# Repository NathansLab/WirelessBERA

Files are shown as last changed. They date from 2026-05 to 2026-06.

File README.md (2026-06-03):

# Wireless BERA

**Wireless Biopotential Electrode Recording Amplifier**

A wireless, battery-powered biopotential recording system for EEG and auditory brainstem response (ABR/BERA) measurements.

> **BERA** stands for two things in this project:
> - **B**rainstem **E**voked **R**esponse **A**udiometry — the clinical application
> - **B**iopotential **E**lectrode **R**ecording **A**mplifier — the hardware

---

## Hardware

**MCU:** ESP32-S3-WROOM-1 — Wi-Fi 802.11 b/g/n + Bluetooth 5.0 LE

**Analog Front-End:**
- LTC6373 programmable-gain instrumentation amplifier (Gain: 0.25, 0.5, 1, 2, 4, 8, 16)
- TAC5212 24-bit ADC via I²S
- Infineon IM73A135 differential MEMS microphone (stimulus/environment monitoring)
- Driven Right Leg (DRL) circuit via OPA376 (active CMR)

**Power** — see [PowerArchitecture.pdf](docs/PowerArchitecture.pdf):

Power Architecture
- BQ24074 single-cell Li-Ion charger
- TPS63000 buck-boost → 3.5 V regulated
- TPS65132W dual charge-pump → ±5.5 V raw
- TPS7A39 dual ultra-low-noise LDO → ±5 V (analog section)
- TPS7A94 LDO → 3.3 V analog
- TPS7A2033 LDO → 3.3 V digital
- Star-topology and LC filters on all analog supply rails

**Peripherals:** MicroSD (SDMMC 4-bit), USB-C (USB 2.0 + ESD)

**PCB:** 4-layer, split GNDA/GNDD

### Daughterboard
Optional plug-in for standalone LTC6373 evaluation at fixed Gain = 16. Stacking multiple daughterboards parallels the INA inputs, reducing equivalent input noise by √n.

---

>  **v1.0 — Pre-production prototype. Not yet fabricated.**

## 3D Renderings

### Stacked Assembly (Main Board + 3x Daughterboards)
Three LTC6373 Daughterboards stacked on top of the main Wireless BERA board to parallel the inputs and reduce equivalent input noise by $\sqrt{n}$.

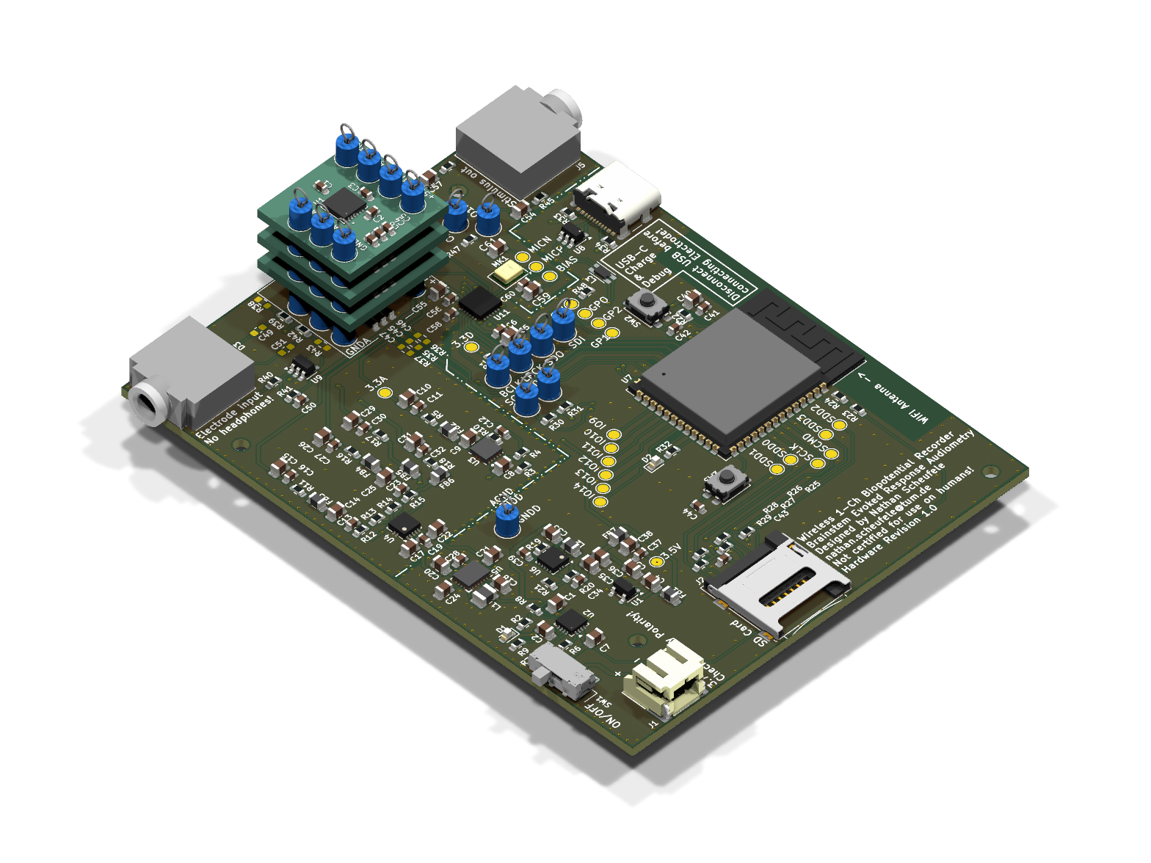
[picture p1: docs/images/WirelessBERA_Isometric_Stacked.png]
Wireless BERA Stacked Isometric


---

## Tools

- **EDA:** KiCad 10
- **Fabrication target:** Aisler (4-layer, HASL)
- **Firmware:** ESP-IDF (ESP32-S3) — see `firmware/`
- **Hardware Auditing & Design Review:** [kicad-happy](https://github.com/aklofas/kicad-happy) (located locally in `kicad-happy/`)

### Running the Hardware Audit
To perform a full design review of the schematic, layout, and EMC pre-compliance:
```bash
# Schematic Analysis
/opt/homebrew/bin/python3 kicad-happy/skills/kicad/scripts/analyze_schematic.py hardware/WirelessBERA.kicad_sch --output scratch/sch_analysis.json

# PCB Layout Analysis
/opt/homebrew/bin/python3 kicad-happy/skills/kicad/scripts/analyze_pcb.py hardware/WirelessBERA.kicad_pcb --full --output scratch/pcb_analysis.json

# Cross-Domain Verification
/opt/homebrew/bin/python3 kicad-happy/skills/kicad/scripts/cross_analysis.py --schematic scratch/sch_analysis.json --pcb scratch/pcb_analysis.json --output scratch/cross_analysis_results.json

# EMC Pre-Compliance Audit
/opt/homebrew/bin/python3 kicad-happy/skills/emc/scripts/analyze_emc.py --schematic scratch/sch_analysis.json --pcb scratch/pcb_analysis.json --output scratch/emc_analysis.json
```
---

## Upstream Tool Updates & Custom Features

The local copy of `kicad-happy/` contains custom extensions (such as the custom footprint/package verification checks in `datasheet_verify.py` and saving logic in `analyze_schematic.py`). 

To pull future improvements from the upstream [kicad-happy repository](https://github.com/aklofas/kicad-happy) while keeping custom modifications:

1. Configure the upstream remote inside `kicad-happy/`:
   ```bash
   cd kicad-happy
   git remote add upstream https://github.com/aklofas/kicad-happy.git
   ```
2. Fetch and merge upstream changes:
   ```bash
   git fetch upstream
   git merge upstream/main
   ```

> [!IMPORTANT]
> **AI Agent Reminder / Instruction:**
> When resuming or initiating a design audit, check if there are new updates in the upstream `kicad-happy` repository. Fetch them, merge them into our local directory, and verify that the custom footprint verification code inside `skills/datasheets/scripts/datasheet_verify.py` and output logic inside `skills/kicad/scripts/analyze_schematic.py` are preserved and function correctly.

---

## Author

Nathan Scheufele

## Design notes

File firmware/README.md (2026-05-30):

# Firmware
ESP-IDF firmware for ESP32-S3 will be added here.

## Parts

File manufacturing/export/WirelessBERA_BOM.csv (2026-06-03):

Reference | Qty | Value | Footprint | MPN | Manufacturer | Chosen_Distributor | Datasheet | Validated | DNP | Notes
C1,C2,C7,C18,C20,C21,C24 | 7 | 4.7u | Capacitor_SMD:C_0805_2012Metric | C0805C475K4PACTU
C3-C5,C8-C10,C14,C15,C17,C22,C25,C26,C29,C31,C33,C35,C36,C38,C56 | 19 | 10u | Capacitor_SMD:C_0805_2012Metric | C0805C106K4PACTU
C6,C11,C16,C19,C27,C30,C32,C37,C39,C41-C47,C57,C61 | 18 | 100n | Capacitor_SMD:C_0603_1608Metric | C0603C104K5RACTU
C12,C50,C59 | 3 | 1u | Capacitor_SMD:C_0603_1608Metric | C0603C105K8PACTU
C13,C23 | 2 | 10n | Capacitor_SMD:C_0603_1608Metric | C0603C103G8GACTU
C28 | 1 | 2.2u | Capacitor_SMD:C_0603_1608Metric | C0603C225K8PACTU
C34 | 1 | 4.7p | Capacitor_SMD:C_0603_1608Metric | C0603C479C4HACTU
C40,C55,C58,C60,C62 | 5 | 22u | Capacitor_SMD:C_0805_2012Metric | GRM21BR60J226ME39L
C48,C53 | 2 | 10u | Capacitor_SMD:C_0603_1608Metric | GRM188R61C106KE15D
C49,C52 | 2 | TBD | Capacitor_SMD:C_0603_1608Metric |  |  |  |  |  | DNP
C51 | 1 | 1n | Capacitor_SMD:C_0603_1608Metric | C1608C0G1H102J080AE
C54 | 1 | 180p | Capacitor_SMD:C_0603_1608Metric | C0603C181J5GACTU
D1,D2 | 2 | LED | LED_SMD:LED_0603_1608Metric | 150060VS75000
D3 | 1 | CMKD6000 | Package_TO_SOT_SMD:SOT-363_SC-70-6 | CMKD6000 TR PBFREE |  |  | https://www.mouser.de/datasheet/3/312/1/CMKD6000.pdf
FB1-FB7 | 7 | FerriteBead | Inductor_SMD:L_0805_2012Metric | 742792040 |  |  | https://www.we-online.com/en/components/products/WE-CBF#742792040
J1 | 1 | Conn_01x02 | Connector_JST:JST_PH_S2B-PH-SM4-TB_1x02-1MP_P2.00mm_Horizontal | S2B-PH-SM4-TB(LF)(SN)
J2,J3 | 2 | PinHeader_01x01_2.54mm_Vertical | Connector_PinHeader_2.54mm:PinHeader_1x01_P2.54mm_Vertical | 61300111121 |  |  | https://www.we-online.com/components/products/datasheet/61300111121.pdf
J4 | 1 | Micro_SD_Card | Connector_Card:microSD_HC_Wuerth_693072010801 | 693072010801 |  |  | https://www.we-online.com/components/products/datasheet/693072010801.pdf
J5 | 1 | USB_C_Receptacle | Connector_USB:USB_C_Receptacle_GCT_USB4105-xx-A_16P_TopMnt_Horizontal | 629722000214 |  |  | https://www.usb.org/sites/default/files/documents/usb_type-c.zip
J6,J11 | 2 | AudioJack3 | Connector_Audio:Jack_3.5mm_CUI_SJ1-3523N_Horizontal | SJ1-3523N
J7,J8,J10,J12 | 4 | PinHeader_01x04_2.54mm_Vertical | Connector_PinHeader_2.54mm:PinHeader_1x04_P2.54mm_Vertical | 61300411121 |  |  | https://www.we-online.com/components/products/datasheet/61300411121.pdf
J9 | 1 | PinHeader_01x03_2.54mm_Vertical | Connector_PinHeader_2.54mm:PinHeader_1x03_P2.54mm_Vertical | 61300311121 |  |  | https://www.we-online.com/components/products/datasheet/61300311121.pdf
J13 | 1 | PinHeader_01x02_2.54mm_Vertical | Connector_PinHeader_2.54mm:PinHeader_1x02_P2.54mm_Vertical | 61300211121 |  |  | https://www.we-online.com/components/products/datasheet/61300211121.pdf
L1 | 1 | 4.7uH | Inductor_SMD:L_1008_2520Metric | 1269AS-H-4R7M=P2 |  |  | https://www.murata.com/en-us/products/productdata/8801124458526/DS0028.pdf
L2 | 1 | 2.2u | Inductor_SMD:L_0805_2012Metric | LQM21PN2R2NGCD |  |  | https://www.murata.com/en-us/products/productdata/8801124458526/DS0028.pdf
L3 | 1 | WE_CNSW_744232090 | Inductor_SMD:L_CommonMode_Wurth_WE-CNSW-1206 | 744232090 |  |  | https://www.we-online.com/components/products/datasheet/744232090.pdf
MK1 | 1 | IM73A135V01 | Sensor_Audio:Infineon_PG-LLGA-5-2 | IM73A135V01XTSA1 |  |  | https://www.infineon.com/dgdl/Infineon-IM73A135-DataSheet-v01_00-EN.pdf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
R1,R5,R11,R16-R18 | 6 | 1R | Resistor_SMD:R_0603_1608Metric | CRCW06031R00FKEA
R2,R7,R33,R34 | 4 | 5.1k | Resistor_SMD:R_0603_1608Metric | CRCW06035K10FKEA
R3,R4,R6,R13,R14,R22-R31,R43,R50 | 17 | 10k | Resistor_SMD:R_0603_1608Metric | CRCW060310K0FKEA
R8 | 1 | 1.1k | Resistor_SMD:R_0603_1608Metric | CRCW06031K10FKEA
R9 | 1 | 2.2k | Resistor_SMD:R_0603_1608Metric | CRCW06032K20FKEA
R10 | 1 | 22.1k | Resistor_SMD:R_0603_1608Metric | CRCW060322K1FKEA
R12 | 1 | 32.4k | Resistor_SMD:R_0603_1608Metric | CRCW060332K4FKEA
R15 | 1 | 42.2k | Resistor_SMD:R_0603_1608Metric | CRCW060342K2FKEA
R19 | 1 | 100R | Resistor_SMD:R_0603_1608Metric | CRCW0603100RFKEA
R20 | 1 | 1.2M | Resistor_SMD:R_0603_1608Metric | CRCW06031M20FKEA
R21 | 1 | 200k | Resistor_SMD:R_0603_1608Metric | CRCW0603200KFKEA
R32 | 1 | 330R | Resistor_SMD:R_0603_1608Metric | CRCW0603330RFKEA
R35-R37 | 3 | 10k | Resistor_SMD:R_0603_1608Metric | CRCW060310K0FKEA |  |  |  |  | DNP
R38,R45 | 2 | TBD | Resistor_SMD:R_0603_1608Metric |  |  |  |  |  | DNP
R39,R42,R44 | 3 | 1M | Resistor_SMD:R_0603_1608Metric | CRCW06031M00FKEA
R40 | 1 | 4.99k | Resistor_SMD:R_0603_1608Metric | CRCW06034K99FKEA
R41 | 1 | 110k | Resistor_SMD:R_0603_1608Metric | CRCW0603110KFKEA
R46,R49 | 2 | 0R | Resistor_SMD:R_0603_1608Metric | CRCW06030000Z0EA
R47,R48 | 2 | 10R | Resistor_SMD:R_0603_1608Metric | CRCW060310R0FKEA
SW1 | 1 | SW_SPDT | Button_Switch_SMD:SW_SPDT_CK_JS102011SAQN | JS102011SAQN |  |  | https://www.ckswitches.com/media/1422/js.pdf
SW2,SW3 | 2 | SW_Push | Button_Switch_SMD:SW_SPST_EVQP2_MiddlePushTravel_H2.5mm | EVQ-P2P02M |  |  | https://4donline.ihs.com/images/VipMasterIC/IC/PANA/PANAS38695/PANAS38695-1.pdf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
U1 | 1 | TPS7A2033PDBVR | Package_TO_SOT_SMD:SOT-23-5 | TPS7A2033PDBVR |  |  | https://www.ti.com/lit/ds/symlink/tps7a20.pdf
U2 | 1 | BQ24074RGT | Package_DFN_QFN:VQFN-16-1EP_3x3mm_P0.5mm_EP1.6x1.6mm | BQ24074RGTR |  |  | http://www.ti.com/lit/ds/symlink/bq24074.pdf
U3 | 1 | TPS7A94 | BERA Project Specific Footprints:TPS7A94_WSON-10 | TPS7A9401DSCR |  |  | https://www.ti.com/lit/ds/symlink/tps7a94.pdf
U4 | 1 | TPS7A39 | Package_SON:Texas_S-PVSON-N10_ThermalVias | TPS7A3901DSCR |  |  | https://www.ti.com/lit/ds/symlink/tps7a39.pdf
U5 | 1 | TPS65132W | BERA Project Specific Footprints:TPS65132W_WQFN-20-TI | TPS65132WRVCR |  |  | https://www.ti.com/lit/gpn/tps65132
U6 | 1 | TPS63000 | Package_SON:Texas_DRC0010J_ThermalVias | TPS63000DRCR |  |  | http://www.ti.com/lit/ds/symlink/tps63000.pdf
U7 | 1 | ESP32-S3-WROOM-1 | RF_Module:ESP32-S3-WROOM-1 | ESP32-S3-WROOM-1-N16R8 |  |  | https://www.espressif.com/sites/default/files/documentation/esp32-s3-wroom-1_wroom-1u_datasheet_en.pdf
U8 | 1 | WE-TVS-82400102 | Package_TO_SOT_SMD:SOT-23-6 | 82400102 |  |  | https://www.we-online.com/components/products/datasheet/82400102.pdf
U9 | 1 | OPA376xxDBV | Package_TO_SOT_SMD:SOT-23-5 | OPA376AIDBVR |  |  | http://www.ti.com/lit/ds/symlink/opa376.pdf
U10 | 1 | LTC6373 | BERA Project Specific Footprints:LTC6373_DFN-12 | LTC6373IDFM#PBF |  |  | https://www.analog.com/media/en/technical-documentation/data-sheets/ltc6373.pdf
U11 | 1 | TAC5212 | BERA Project Specific Footprints:TAC5212_VQFN24 | TAC5212IRGER |  |  | https://www.ti.com/lit/gpn/tac5212

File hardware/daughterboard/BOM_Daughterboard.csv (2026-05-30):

Refs | Value | Footprint | Qty | DNP
C1 | 180p | Capacitor_SMD:C_0603_1608Metric | 1
C2 | 10u | Capacitor_SMD:C_0603_1608Metric | 1
C3 | 10u | Capacitor_SMD:C_0603_1608Metric | 1
C4 | 100n | Capacitor_SMD:C_0603_1608Metric | 1
C5 | 100n | Capacitor_SMD:C_0603_1608Metric | 1
C6 | 100n | Capacitor_SMD:C_0603_1608Metric | 1
H1 | Header_Pin | TestPoint:TestPoint_Loop_D2.60mm_Drill0.9mm_Beaded | 1
H2 | Header_Pin | TestPoint:TestPoint_Loop_D2.60mm_Drill0.9mm_Beaded | 1
H3 | Header_Pin | TestPoint:TestPoint_Loop_D2.60mm_Drill0.9mm_Beaded | 1
H4 | Header_Pin | TestPoint:TestPoint_Loop_D2.60mm_Drill0.9mm_Beaded | 1
H5 | Header_Pin | TestPoint:TestPoint_Loop_D2.60mm_Drill0.9mm_Beaded | 1
H6 | Header_Pin | TestPoint:TestPoint_Loop_D2.60mm_Drill0.9mm_Beaded | 1
H7 | Header_Pin | TestPoint:TestPoint_Loop_D2.60mm_Drill0.9mm_Beaded | 1
U1 | LTC6373 | BERA Project Specific Footprints:LTC6373_DFN-12 | 1

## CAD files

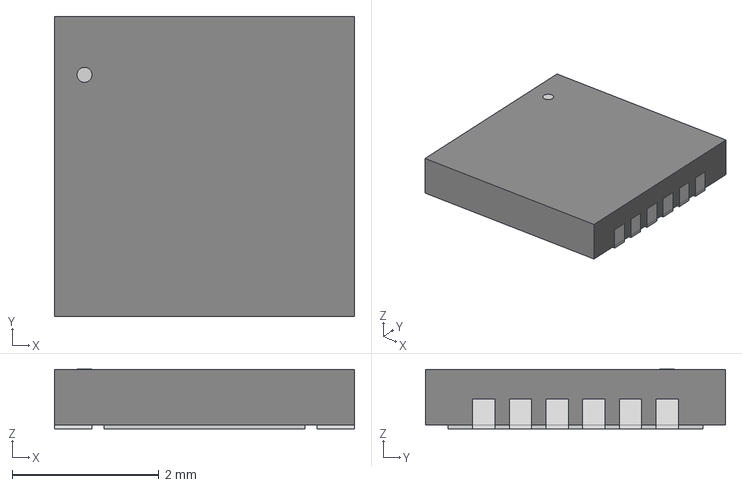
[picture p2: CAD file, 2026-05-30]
hardware/daughterboard/3d_models/LTC6373.step
4.09 x 4.09 x 0.815 mm

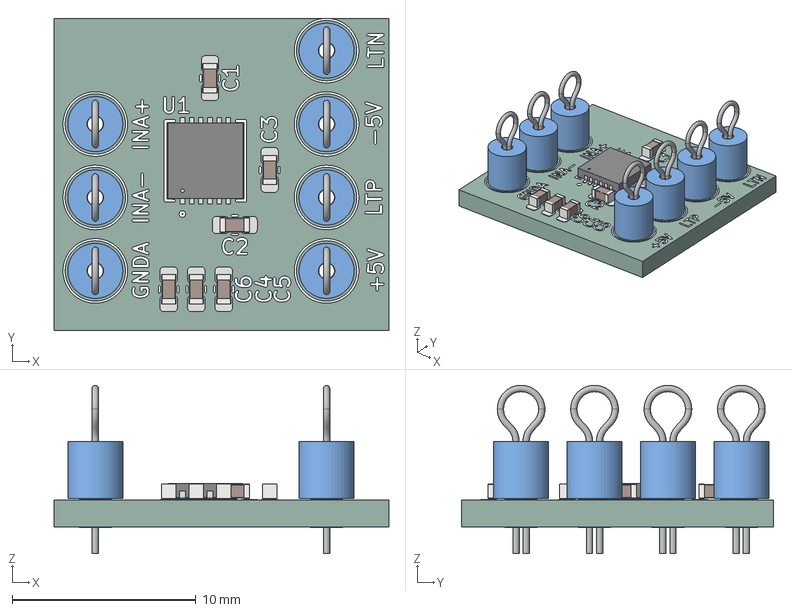
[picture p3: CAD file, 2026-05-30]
hardware/daughterboard/LTC6373_Daughterboard.step
18.2 x 17.0 x 9.17 mm
C_0603_1608Metric x 6
TestPoint_Loop_D2.60mm_Drill0.9mm_Beaded x 7
LTC6373
LTC6373_Daughterboard_pad
LTC6373_Daughterboard_silkscreen
LTC6373_Daughterboard_PCB

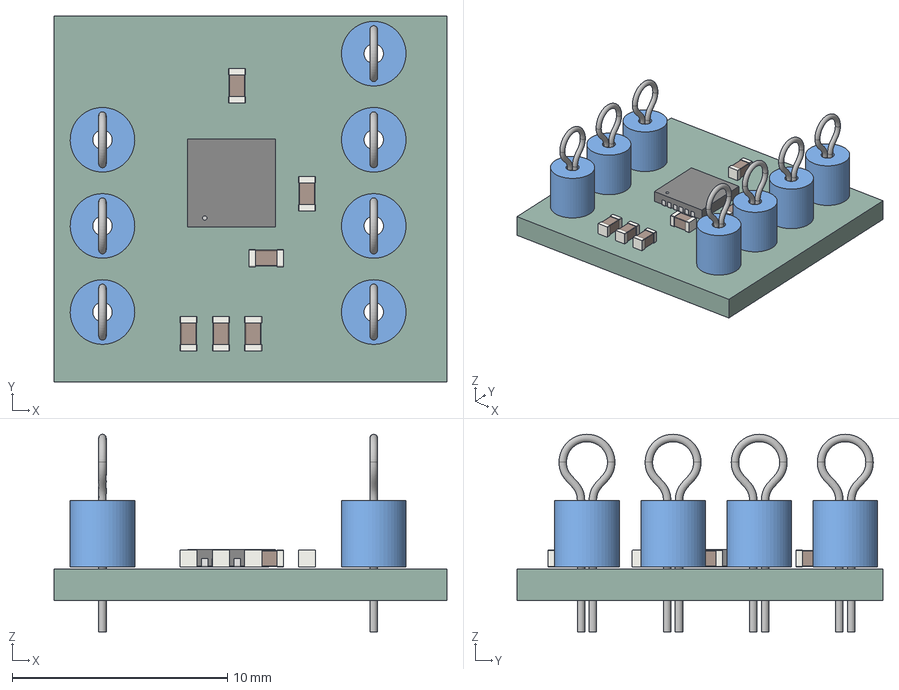
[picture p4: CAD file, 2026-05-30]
manufacturing/export/LTC6373_Daughterboard.step
18.2 x 17.0 x 9.17 mm
C_0603_1608Metric x 6
TestPoint_Loop_D2.60mm_Drill0.9mm_Beaded x 7
LTC6373
LTC6373_Daughterboard_PCB

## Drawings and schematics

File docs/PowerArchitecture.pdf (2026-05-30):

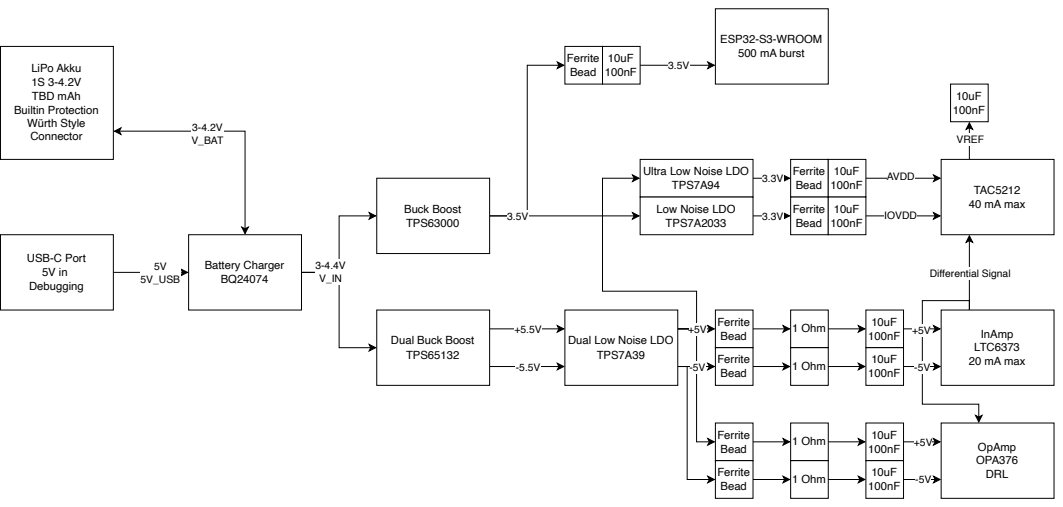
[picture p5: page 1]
LiPo Akku 1S 3-4.2V TBD mAh Builtin Protection Würth Style Connector; 5V 5V_USB; USB-C Port 5V in Debugging; 3-4.2V V_BAT; Battery Charger BQ24074; 3.3V Buck Boost; TPS63000; ESP32-S3-WROOM 500 mA burst; VREF; TAC5212 40 mA max; Ferrite; Bead; 1 Ohm; Differential Signal; InAmp LTC6373 20 mA max; Ferrite Bead; AVDD 10uF; IOVDD 10uF; OpAmp OPA376 DRL; 10uF 100nF 1 Ohm

100nF 3.3V Ultra Low Noise LDO
TPS7A94

Low Noise LDO
TPS7A2033

Dual Buck Boost
TPS65132

Dual Low Noise LDO
TPS7A39

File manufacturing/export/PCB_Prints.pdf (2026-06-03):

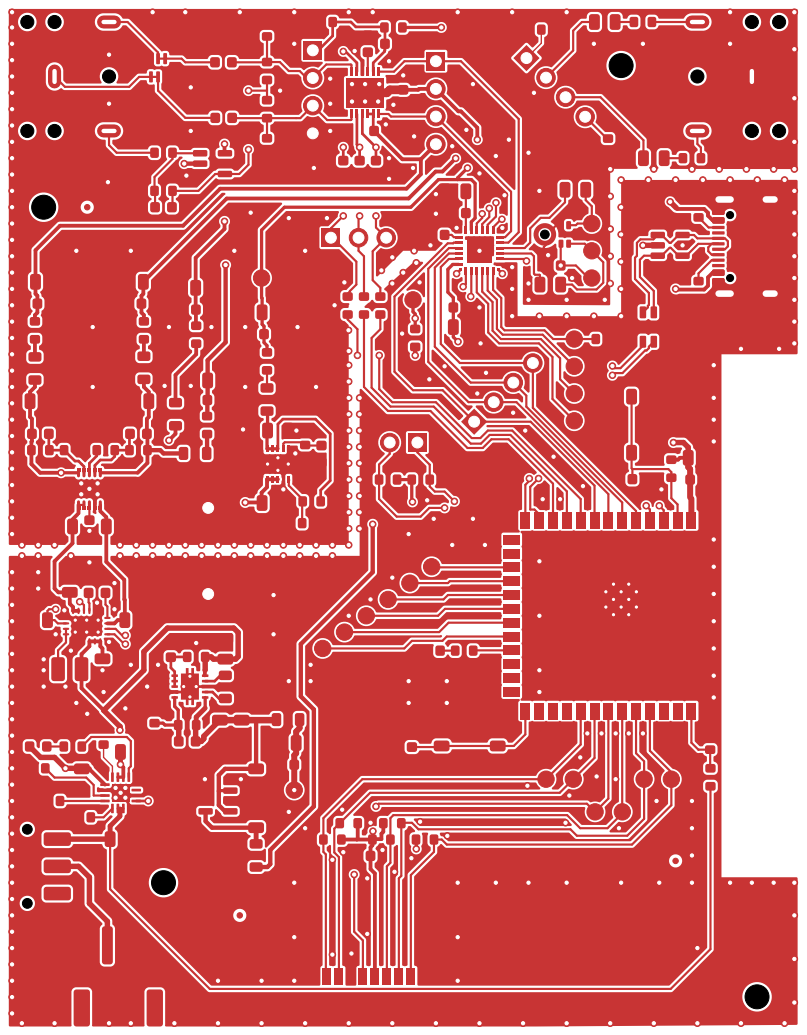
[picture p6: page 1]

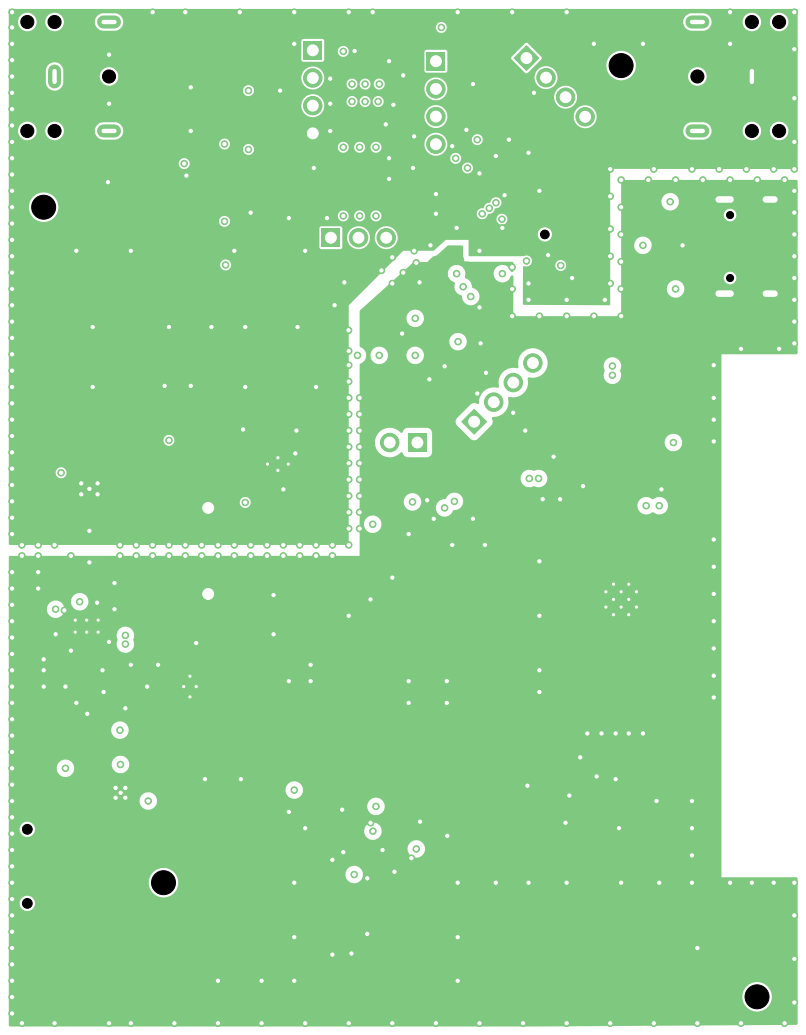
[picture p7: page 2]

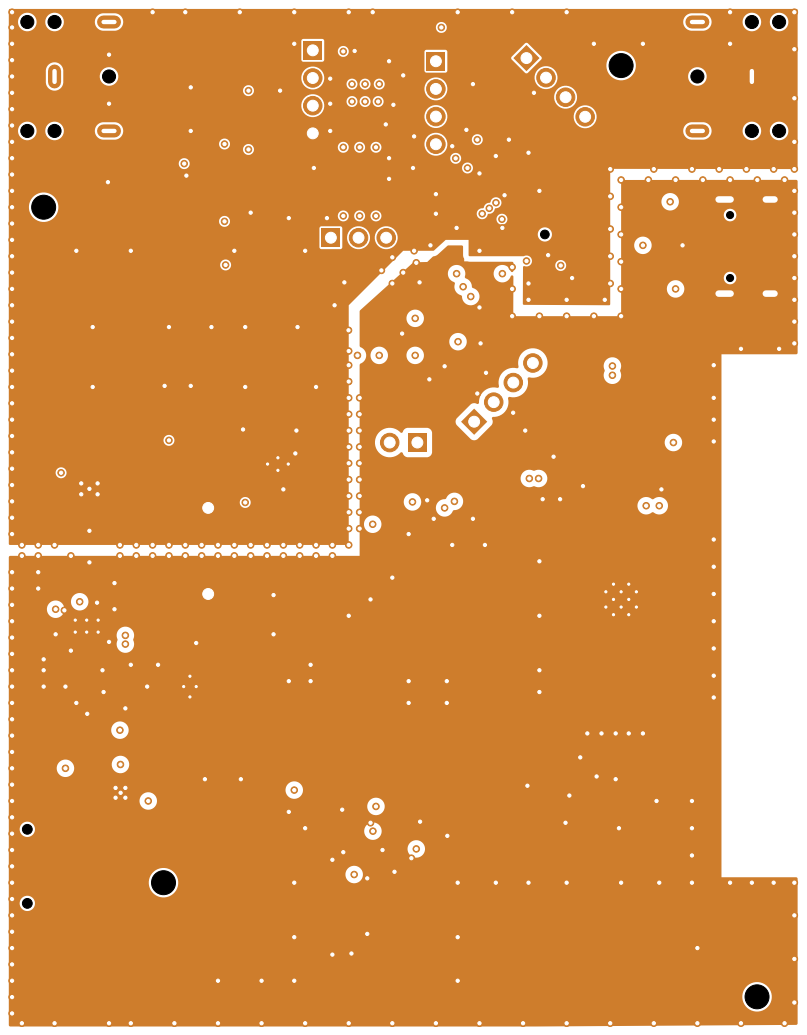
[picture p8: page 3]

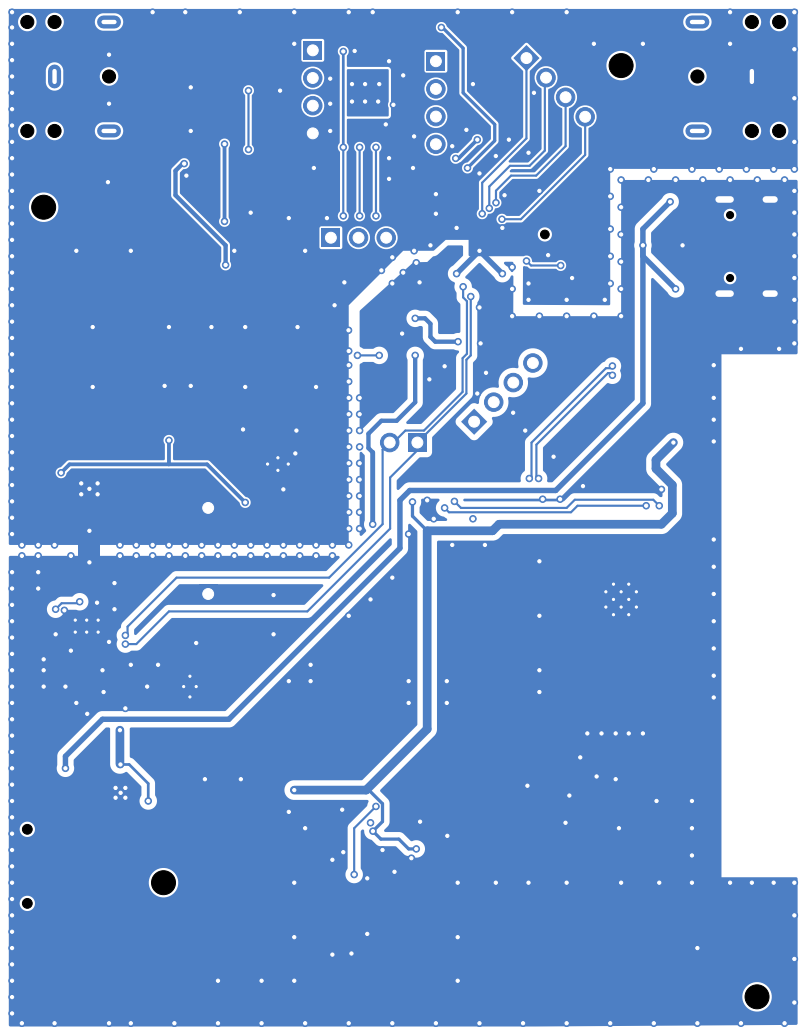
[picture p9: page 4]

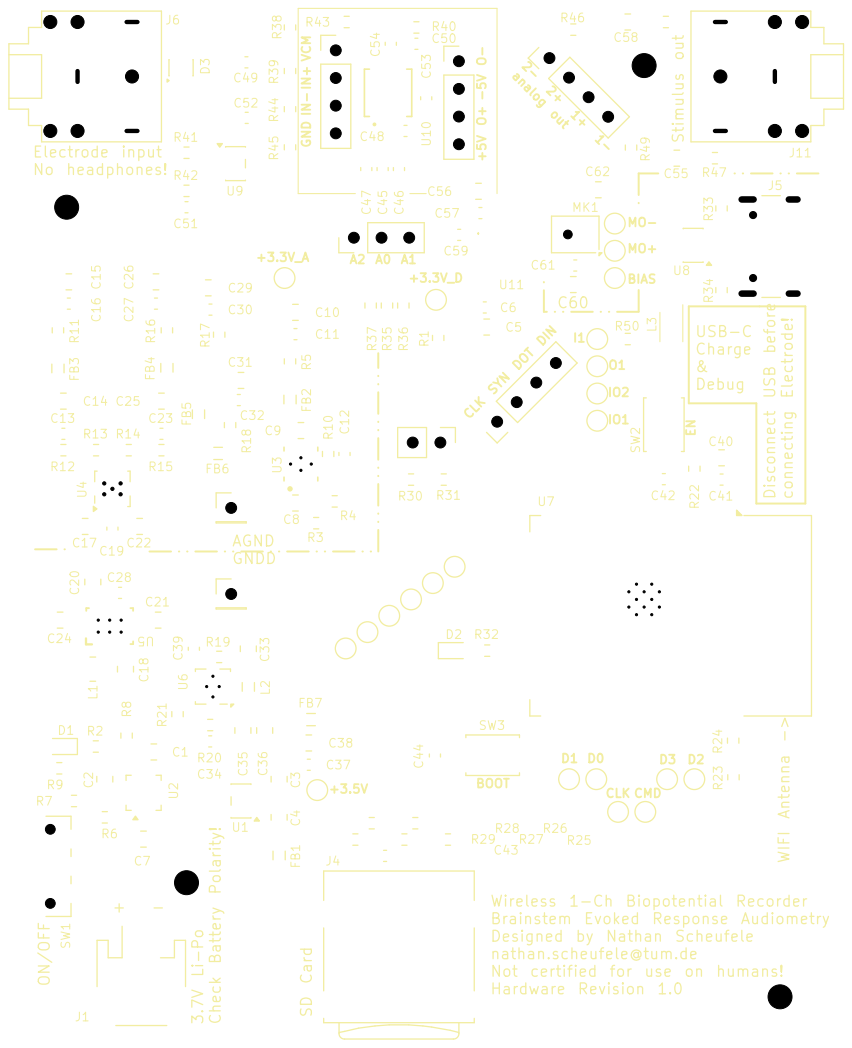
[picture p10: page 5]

analog out Electrode input No headphones! + -

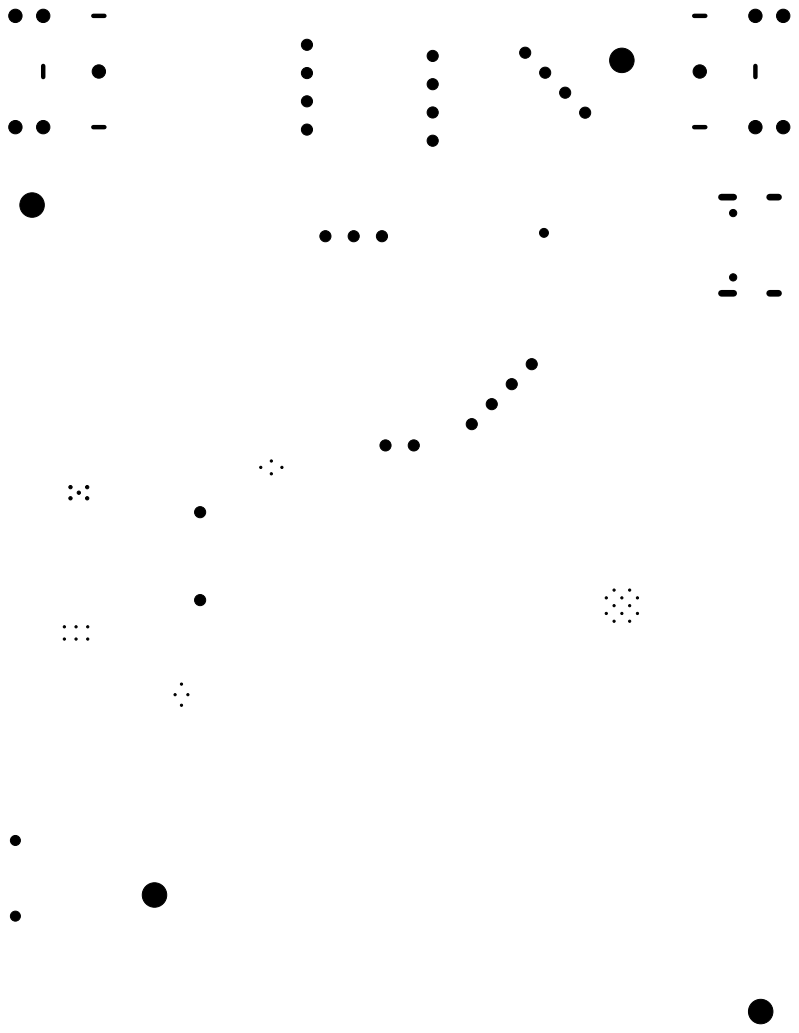
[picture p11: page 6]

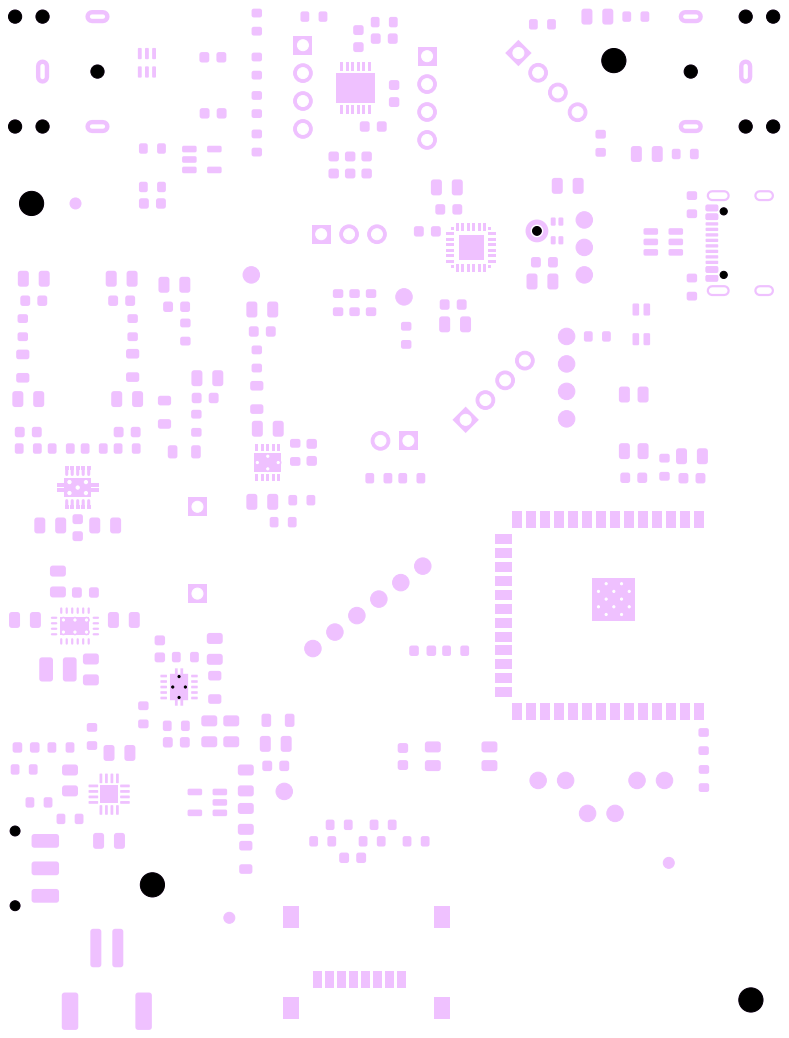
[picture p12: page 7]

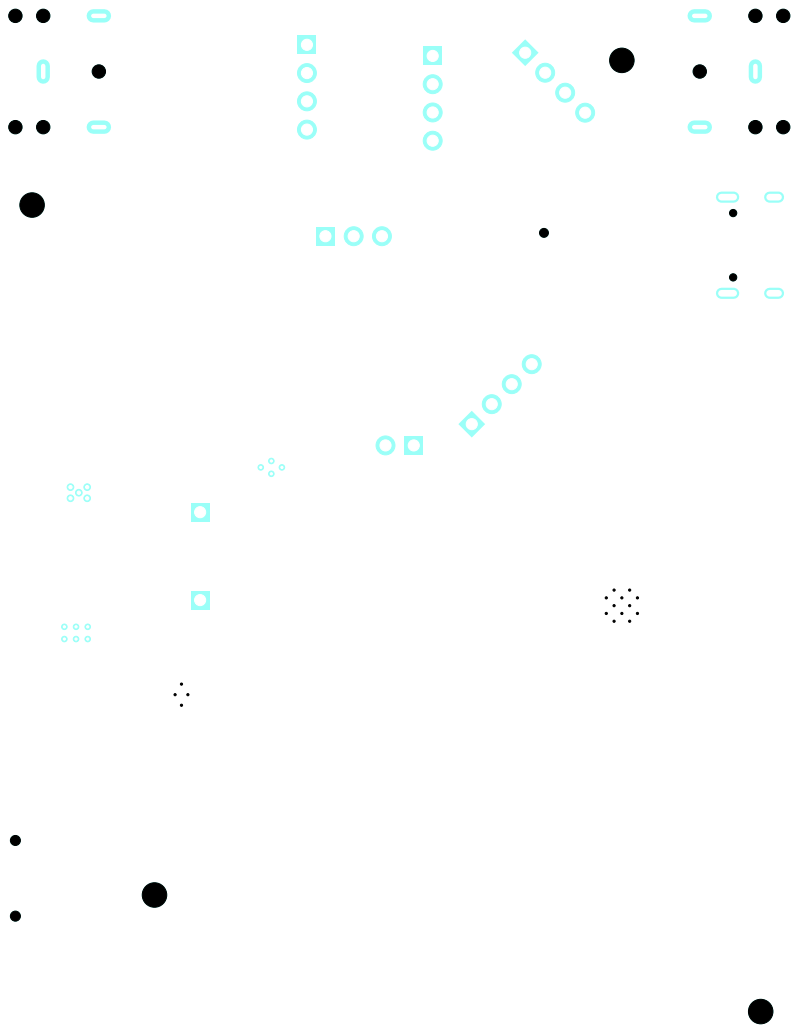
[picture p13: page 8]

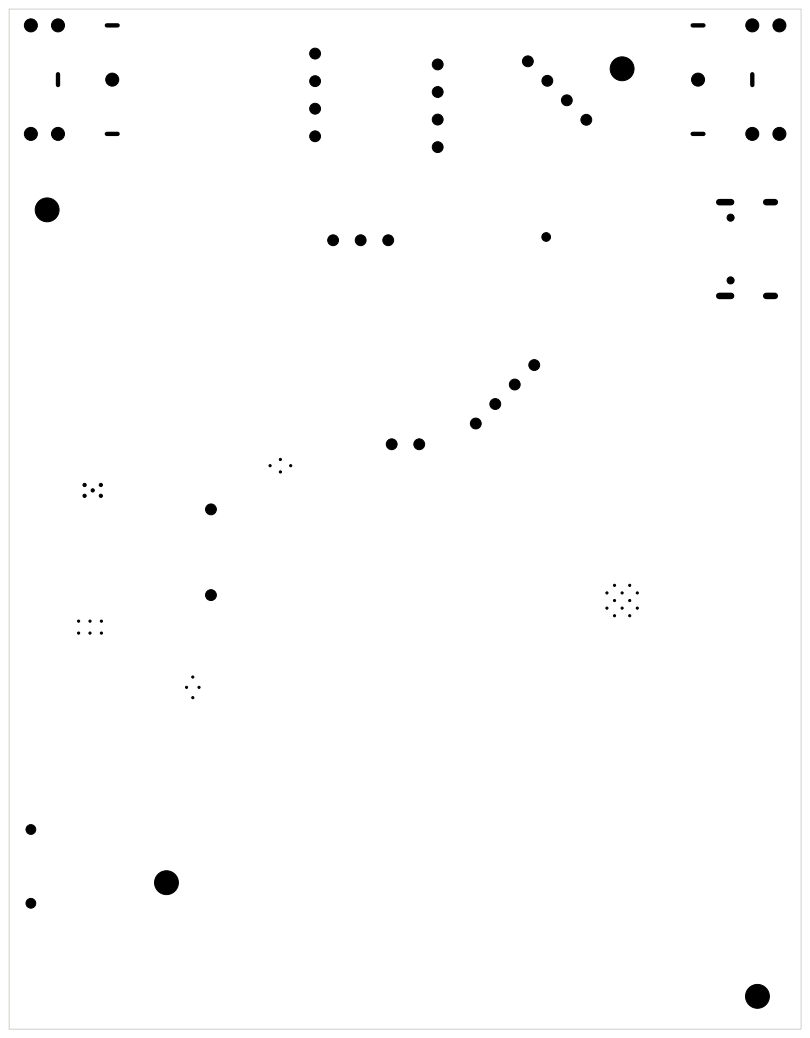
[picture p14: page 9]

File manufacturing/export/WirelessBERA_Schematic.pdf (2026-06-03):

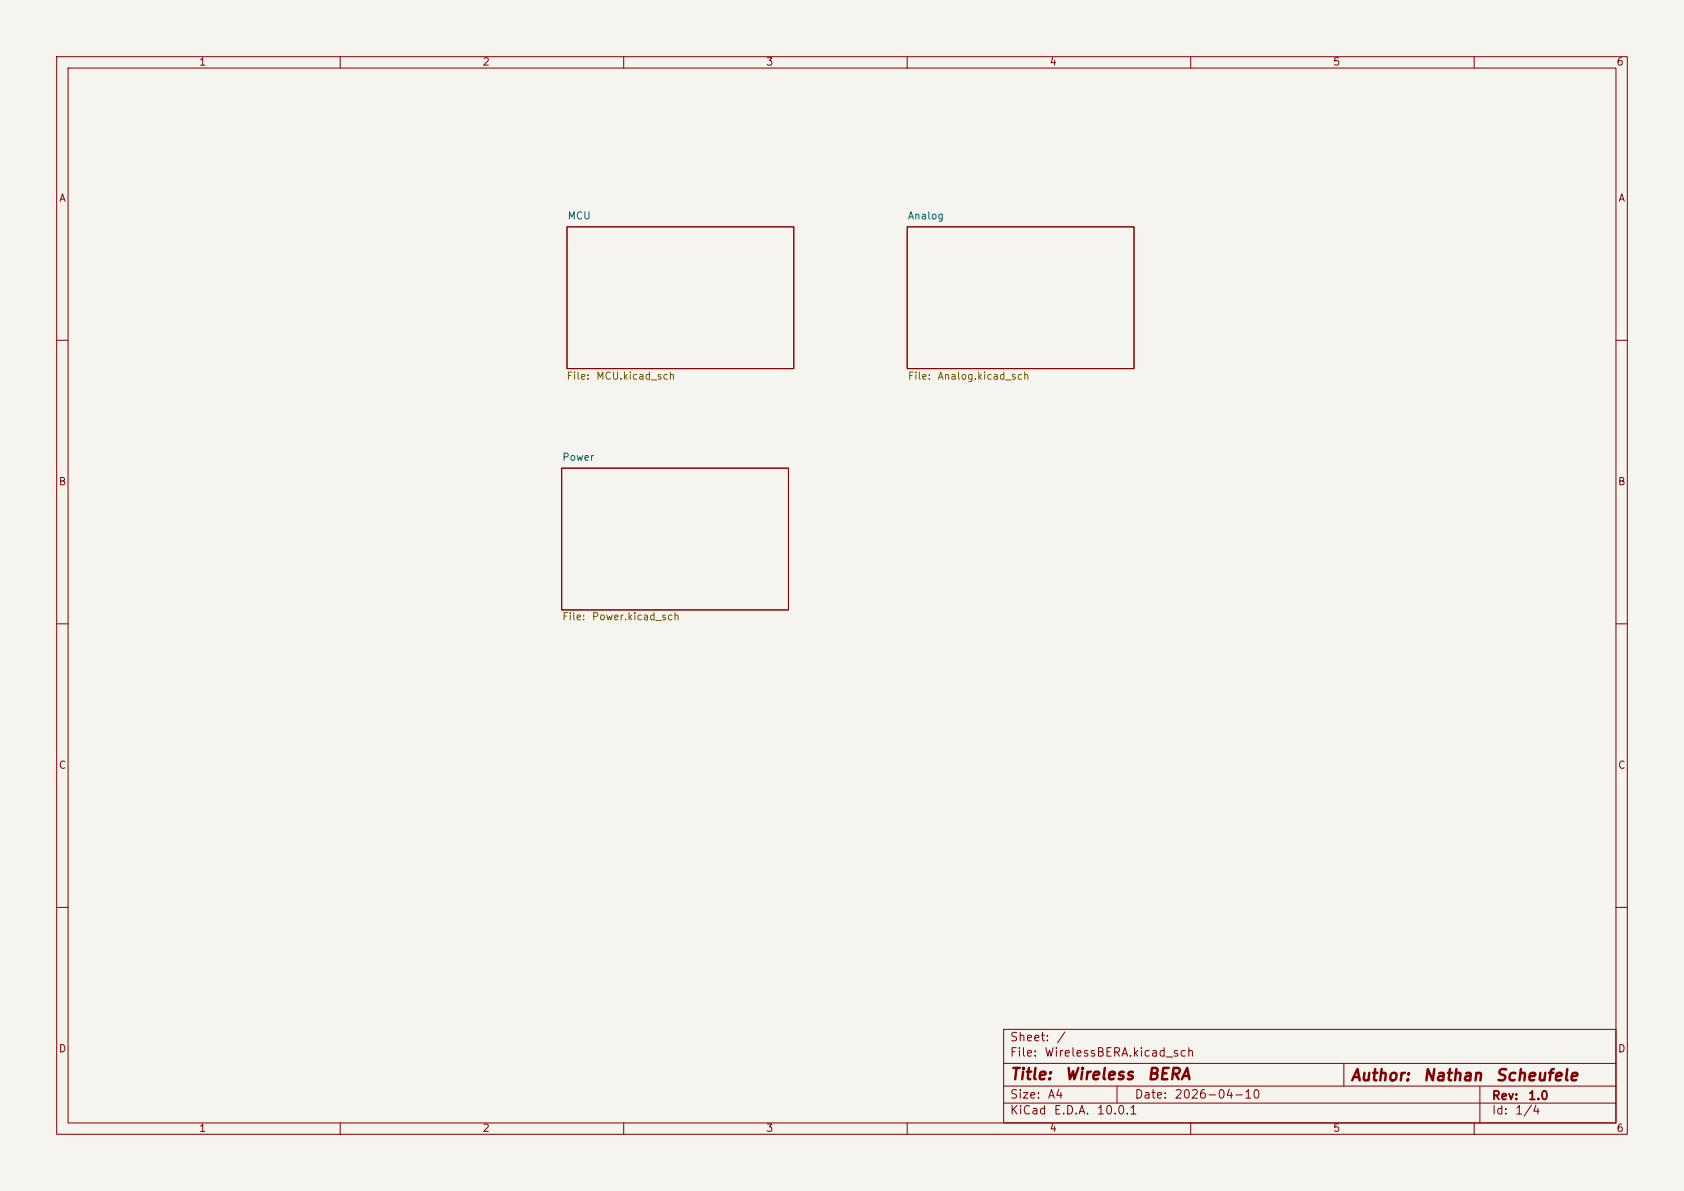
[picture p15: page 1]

File: Analog.kicad_sch Power File: Power.kicad_sch MCU

Title: Wireless BERA | Author: Nathan Scheufele
Size: A4 | | Rev: 1.0
KiCad E.D.A. 10.0.1 | | Id: 1/4

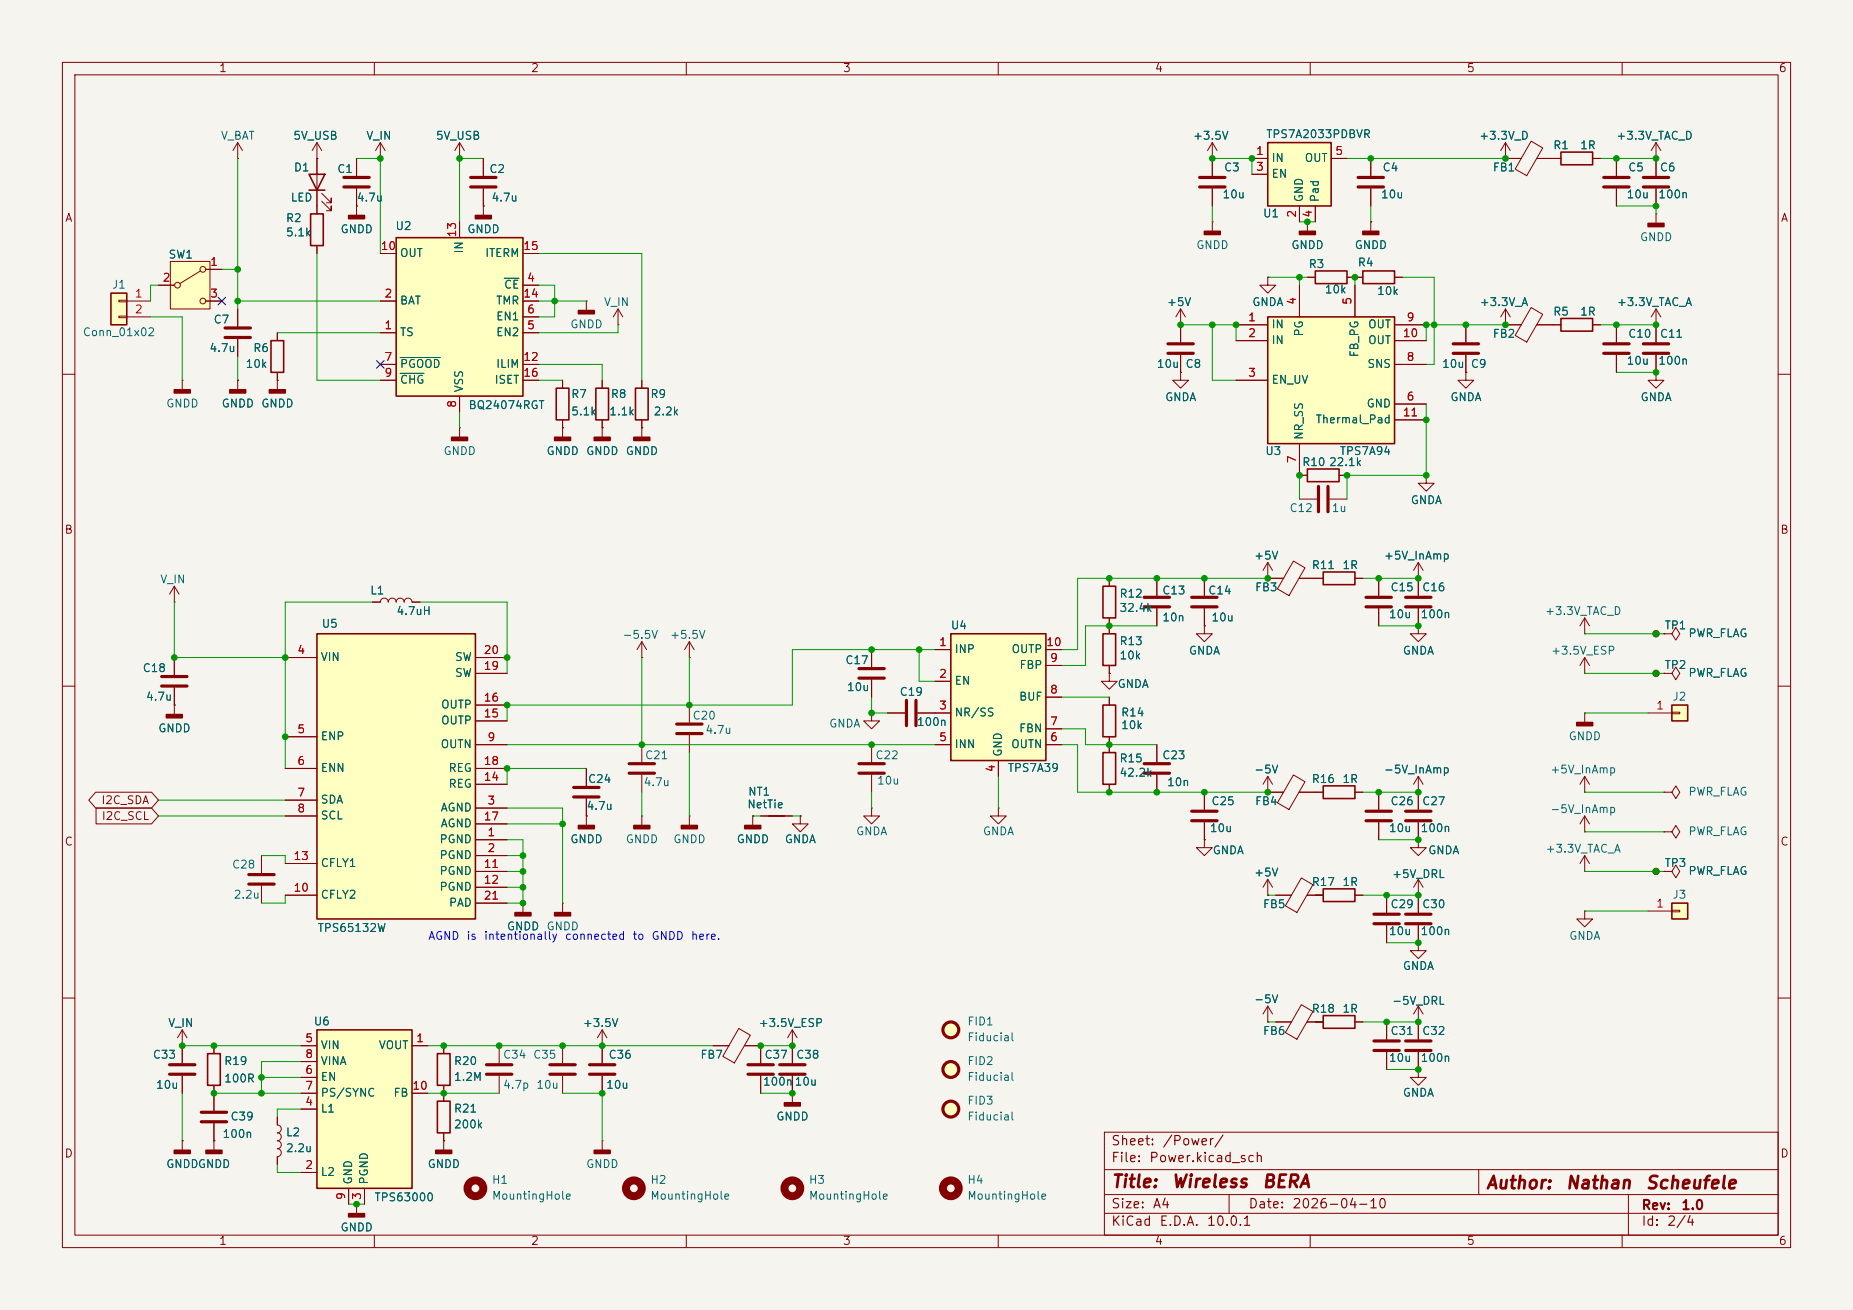
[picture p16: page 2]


IO6 6 | | | DAT2 1 DAT3/CD 2 CMD 3

IO7 7 | SD_CMD
IO15 8 | SD_CLK | TP7 | VDD 4 CLK 5


IN2 polarity reversed intentionally
for easy routting, inverts signal.

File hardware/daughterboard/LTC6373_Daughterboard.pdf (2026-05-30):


Parallel INA daughterboard for noise reduction
BERA
Sheet: /
File: LTC6373_Daughterboard.kicad_sch
Title: LTC6373 Daughterboard

Size: A4 | Rev:
KiCad E.D.A. 10.0.1 | Id: 1/1








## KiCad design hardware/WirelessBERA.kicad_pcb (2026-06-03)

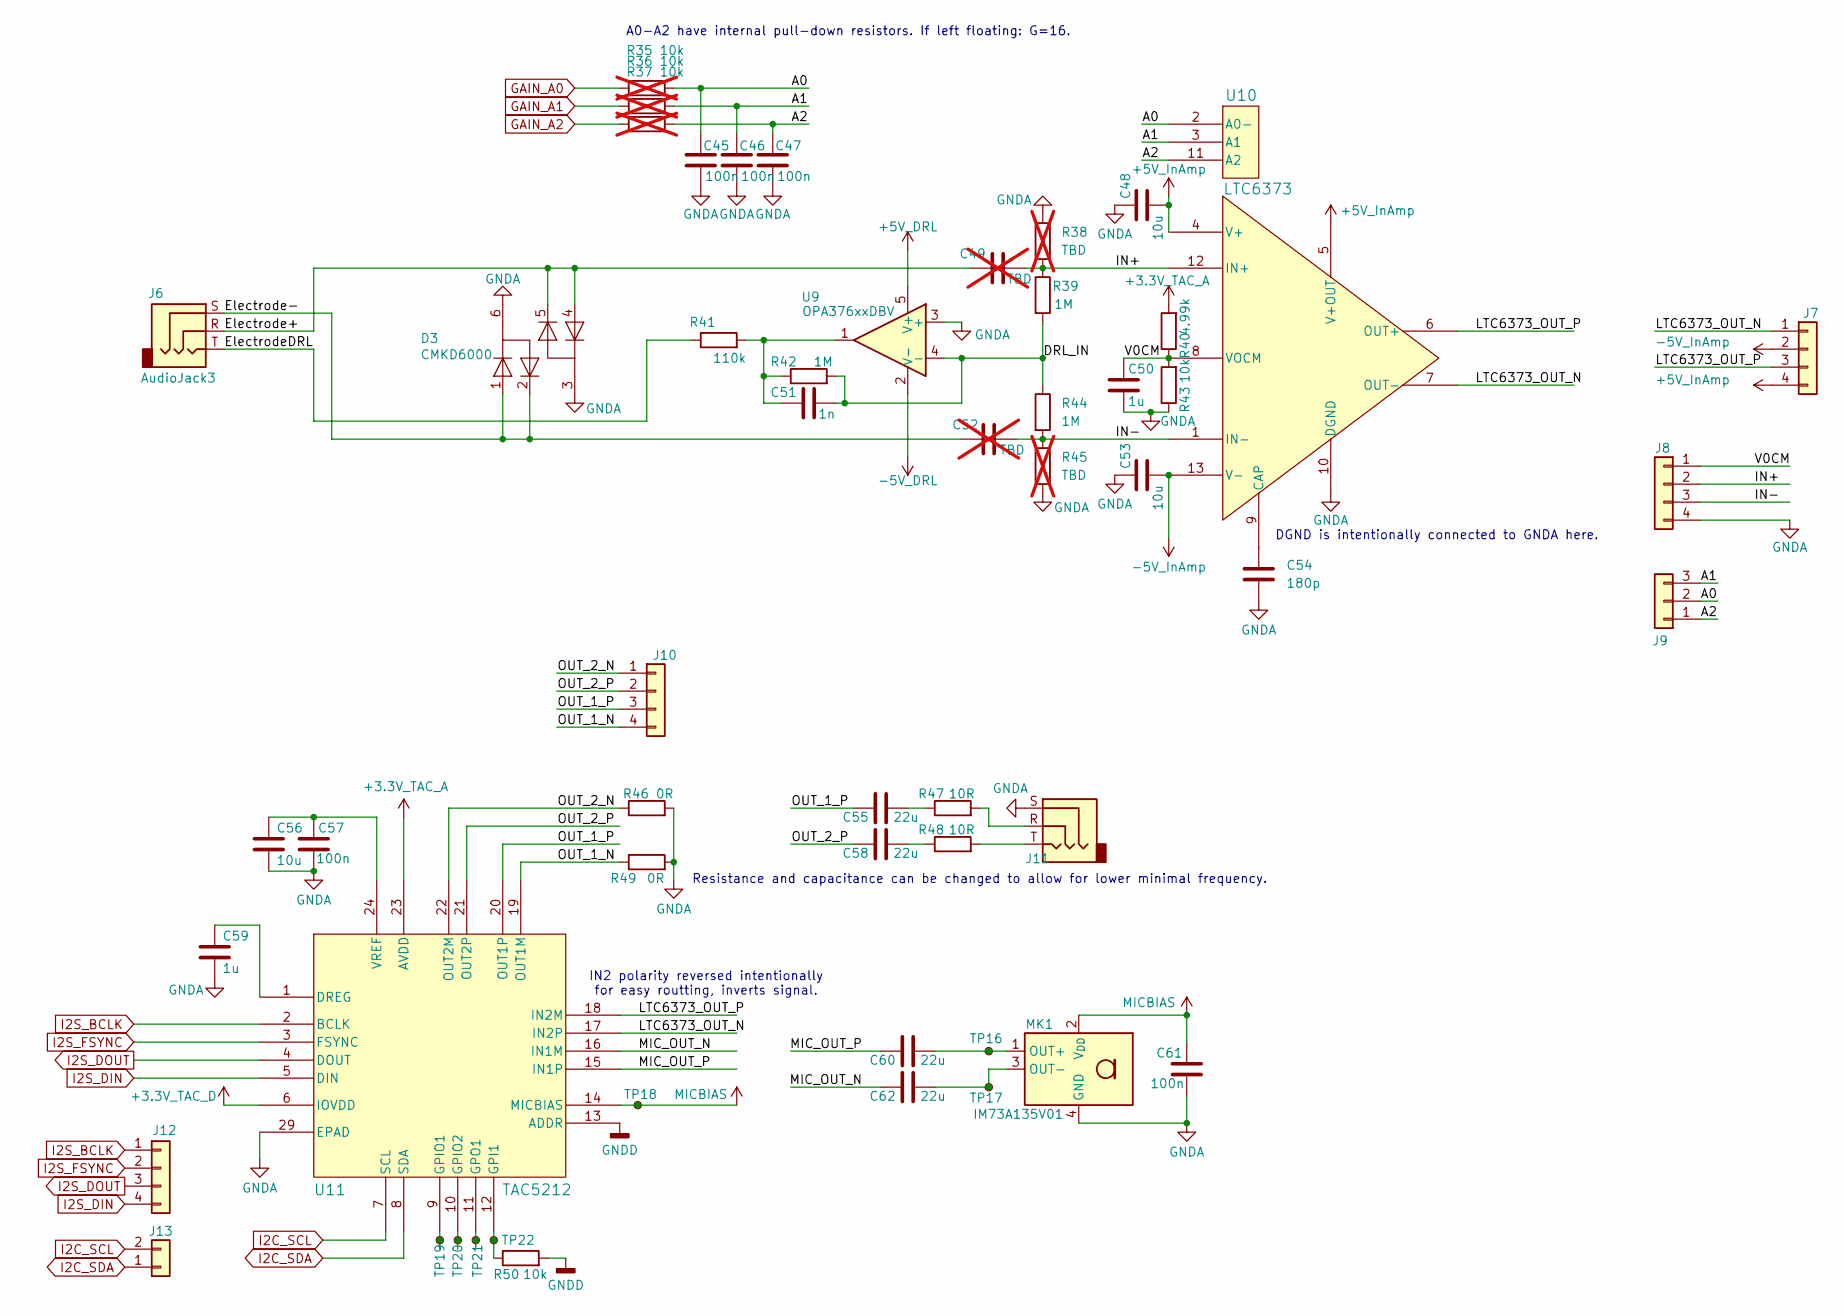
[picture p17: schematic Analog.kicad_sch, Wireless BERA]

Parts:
C45, C46, C47, C57, C61: 100n; C_0603_1608Metric; MPN C0603C104K5RACTU
C48, C53: 10u; C_0603_1608Metric; MPN GRM188R61C106KE15D
C49, C52: TBD; C_0603_1608Metric; not fitted
C50, C59: 1u; C_0603_1608Metric; MPN C0603C105K8PACTU
C51: 1n; C_0603_1608Metric; MPN C1608C0G1H102J080AE
C54: 180p; C_0603_1608Metric; MPN C0603C181J5GACTU
C55, C58, C60, C62: 22u; C_0805_2012Metric; MPN GRM21BR60J226ME39L
C56: 10u; C_0805_2012Metric; MPN C0805C106K4PACTU
D3: CMKD6000; SOT-363_SC-70-6; MPN CMKD6000 TR PBFREE
J6, J11: AudioJack3; Jack_3.5mm_CUI_SJ1-3523N_Horizontal; MPN SJ1-3523N
J7, J8, J10, J12: PinHeader_01x04_2.54mm_Vertical; PinHeader_1x04_P2.54mm_Vertical; MPN 61300411121
J9: PinHeader_01x03_2.54mm_Vertical; PinHeader_1x03_P2.54mm_Vertical; MPN 61300311121
J13: PinHeader_01x02_2.54mm_Vertical; PinHeader_1x02_P2.54mm_Vertical; MPN 61300211121
MK1: IM73A135V01; Infineon_PG-LLGA-5-2; MPN IM73A135V01XTSA1
R35, R36, R37: 10k; R_0603_1608Metric; MPN CRCW060310K0FKEA; not fitted
R38, R45: TBD; R_0603_1608Metric; not fitted
R39, R42, R44: 1M; R_0603_1608Metric; MPN CRCW06031M00FKEA
R40: 4.99k; R_0603_1608Metric; MPN CRCW06034K99FKEA
R41: 110k; R_0603_1608Metric; MPN CRCW0603110KFKEA
R43, R50: 10k; R_0603_1608Metric; MPN CRCW060310K0FKEA
R46, R49: 0R; R_0603_1608Metric; MPN CRCW06030000Z0EA
R47, R48: 10R; R_0603_1608Metric; MPN CRCW060310R0FKEA
TP16, TP17, TP18, TP19, TP20, TP21, TP22: TestPoint_Small; TestPoint_Pad_D1.5mm
U9: OPA376xxDBV; SOT-23-5; MPN OPA376AIDBVR
U10: LTC6373; LTC6373_DFN-12; MPN LTC6373IDFM#PBF
U11: TAC5212; TAC5212_VQFN24; MPN TAC5212IRGER

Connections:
+3.3V_TAC_A: R40.2, U11.23 (AVDD); also elsewhere on the board
+3.3V_TAC_D: U11.6 (IOVDD); also elsewhere on the board
+5V_DRL: U9.5 (V+); also elsewhere on the board
+5V_InAmp: C48.2, J7.4, U10.4 (V+), U10.5 (V+OUT); also elsewhere on the board
-5V_DRL: U9.2 (V-); also elsewhere on the board
-5V_InAmp: C53.2, J7.2, U10.13 (V-); also elsewhere on the board
/Analog/A0: C45.1, J9.2, R35.2, U10.2 (A0-)
/Analog/A1: C46.1, J9.3, R36.2, U10.3 (A1)
/Analog/A2: C47.1, J9.1, R37.2, U10.11 (A2)
/Analog/DRL_IN: C51.2, R39.2, R42.2, R44.1, U9.4 (-)
/Analog/Electrode+: C49.1, D3.4, D3.5, J6.R
/Analog/Electrode-: C52.1, D3.1, D3.2, J6.S
/Analog/ElectrodeDRL: J6.T, R41.1
/Analog/IN+: C49.2, J8.2, R38.2, R39.1, U10.12 (IN+)
/Analog/IN-: C52.2, J8.3, R44.2, R45.1, U10.1 (IN-)
/Analog/LTC6373_OUT_N: J7.1, U10.7 (OUT-), U11.17 (IN2P)
/Analog/LTC6373_OUT_P: J7.3, U10.6 (OUT+), U11.18 (IN2M)
/Analog/MIC_OUT_N: C62.1, U11.16 (IN1M)
/Analog/MIC_OUT_P: C60.1, U11.15 (IN1P)
/Analog/OUT_1_N: J10.4, R49.1, U11.19 (OUT1M)
/Analog/OUT_1_P: C55.1, J10.3, U11.20 (OUT1P)
/Analog/OUT_2_N: J10.1, R46.1, U11.22 (OUT2M)
/Analog/OUT_2_P: C58.1, J10.2, U11.21 (OUT2P)
/Analog/V0CM: C50.1, J8.1, R40.1, R43.2, U10.8 (VOCM)
GAIN_A0: R35.1; also elsewhere on the board
GAIN_A1: R36.1; also elsewhere on the board
GAIN_A2: R37.1; also elsewhere on the board
GNDA: C45.2, C46.2, C47.2, C48.1, C50.2, C53.1, C54.2, C56.2, C57.2, C59.2, C61.2, D3.3, D3.6, J8.4, J11.S, MK1.4 (GND), MK1.5 (GND), R38.1, R43.1, R45.2, R46.2, R49.2, U9.3 (+), U10.10 (DGND), U11.29 (EPAD); also elsewhere on the board
GNDD: R50.2, U11.13 (ADDR); also elsewhere on the board
I2C_SCL: J13.2, U11.7 (SCL); also elsewhere on the board
I2C_SDA: J13.1, U11.8 (SDA); also elsewhere on the board
I2S_BCLK: J12.1, U11.2 (BCLK); also elsewhere on the board
I2S_DIN: J12.4, U11.5 (DIN); also elsewhere on the board
I2S_DOUT: J12.3, U11.4 (DOUT); also elsewhere on the board
I2S_FSYNC: J12.2, U11.3 (FSYNC); also elsewhere on the board
MICBIAS: C61.1, MK1.2 (V_{DD}), TP18.1 (1_1), U11.14 (MICBIAS)
unnamed: C51.1, R41.2, R42.1, U9.1
unnamed: C55.2, R47.1
unnamed: C58.2, R48.1
unnamed: J11.R, R47.2
unnamed: J11.T, R48.2
unnamed: C60.2, MK1.1 (OUT+), TP16.1 (1_1)
unnamed: C62.2, MK1.3 (OUT-), TP17.1 (1_1)
unnamed: C54.1, U10.9 (CAP)
unnamed: C59.1, U11.1 (DREG)
unnamed: R50.1, TP22.1 (1_1), U11.12 (GPI1)
unnamed: TP19.1 (1_1), U11.9 (GPIO1)
unnamed: TP20.1 (1_1), U11.10 (GPIO2)
unnamed: TP21.1 (1_1), U11.11 (GPO1)
unnamed: C56.1, C57.1, U11.24 (VREF)

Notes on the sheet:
Resistance and capacitance can be changed to allow for lower minimal frequency.
IN2 polarity reversed intentionally for easy routting, inverts signal.
DGND is intentionally connected to GNDA here.
A0-A2 have internal pull-down resistors. If left floating: G=16.

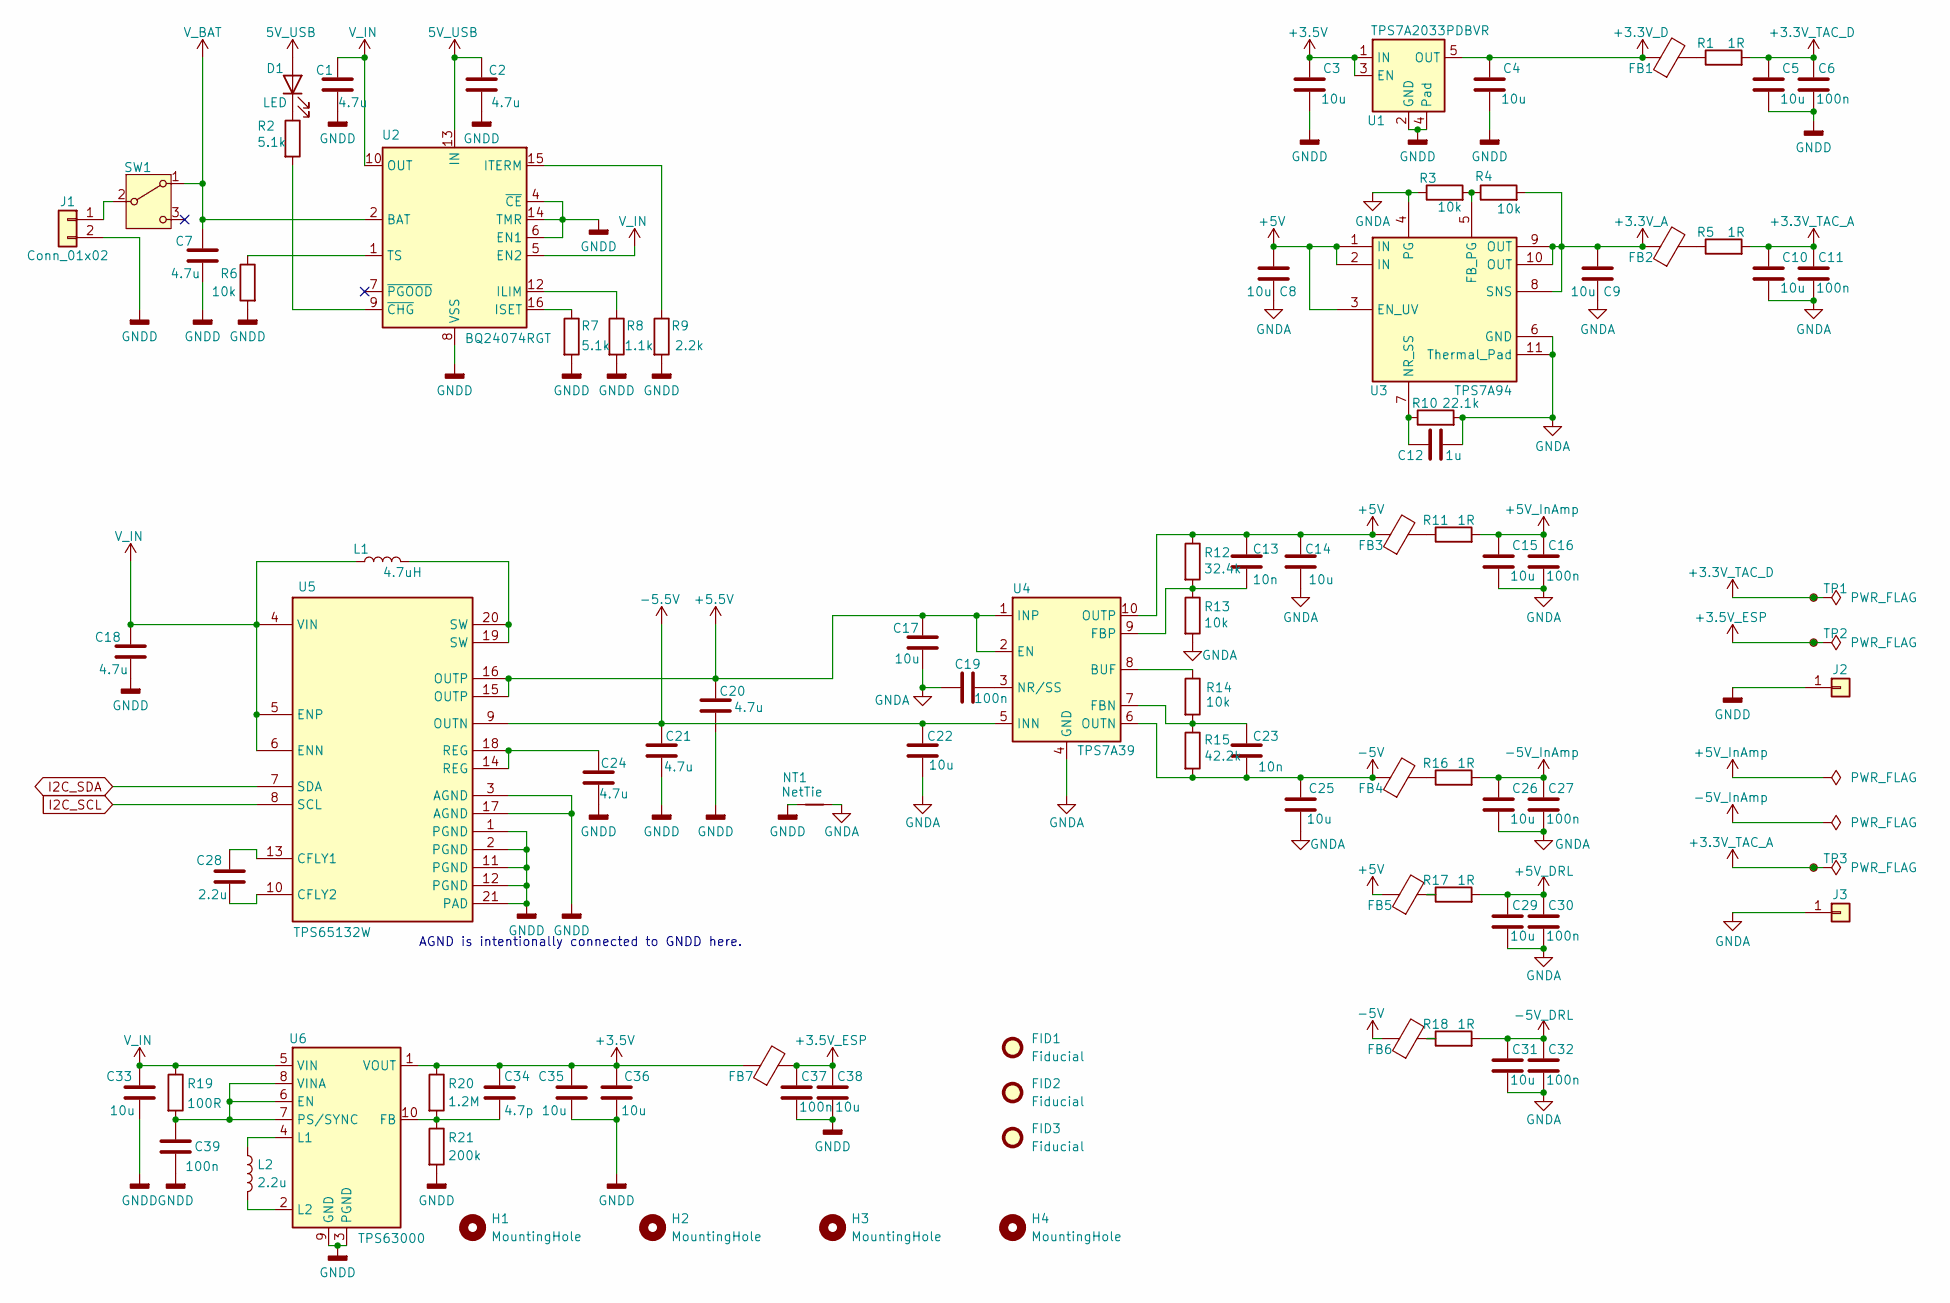
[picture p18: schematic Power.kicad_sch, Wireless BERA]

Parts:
C1, C2, C7, C18, C20, C21, C24: 4.7u; C_0805_2012Metric; MPN C0805C475K4PACTU
C3, C4, C5, C8, C9, C10, C14, C15, C17, C22, C25, C26, C29, C31, C33, C35, C36, C38: 10u; C_0805_2012Metric; MPN C0805C106K4PACTU
C6, C11, C16, C19, C27, C30, C32, C37, C39: 100n; C_0603_1608Metric; MPN C0603C104K5RACTU
C12: 1u; C_0603_1608Metric; MPN C0603C105K8PACTU
C13, C23: 10n; C_0603_1608Metric; MPN C0603C103G8GACTU
C28: 2.2u; C_0603_1608Metric; MPN C0603C225K8PACTU
C34: 4.7p; C_0603_1608Metric; MPN C0603C479C4HACTU
D1: LED; LED_0603_1608Metric; MPN 150060VS75000
FB1, FB2, FB3, FB4, FB5, FB6, FB7: FerriteBead; L_0805_2012Metric; MPN 742792040
FID1, FID2, FID3: Fiducial; Fiducial_0.5mm_Mask1mm
H1, H2, H3, H4: MountingHole; MountingHole_2.2mm_M2
J1: Conn_01x02; JST_PH_S2B-PH-SM4-TB_1x02-1MP_P2.00mm_Horizontal; MPN S2B-PH-SM4-TB(LF)(SN)
J2, J3: PinHeader_01x01_2.54mm_Vertical; PinHeader_1x01_P2.54mm_Vertical; MPN 61300111121
L1: 4.7uH; L_1008_2520Metric; MPN 1269AS-H-4R7M=P2
L2: 2.2u; L_0805_2012Metric; MPN LQM21PN2R2NGCD
NT1: NetTie; NetTie-2_SMD_Pad2.0mm
R1, R5, R11, R16, R17, R18: 1R; R_0603_1608Metric; MPN CRCW06031R00FKEA
R2, R7: 5.1k; R_0603_1608Metric; MPN CRCW06035K10FKEA
R3, R4, R6, R13, R14: 10k; R_0603_1608Metric; MPN CRCW060310K0FKEA
R8: 1.1k; R_0603_1608Metric; MPN CRCW06031K10FKEA
R9: 2.2k; R_0603_1608Metric; MPN CRCW06032K20FKEA
R10: 22.1k; R_0603_1608Metric; MPN CRCW060322K1FKEA
R12: 32.4k; R_0603_1608Metric; MPN CRCW060332K4FKEA
R15: 42.2k; R_0603_1608Metric; MPN CRCW060342K2FKEA
R19: 100R; R_0603_1608Metric; MPN CRCW0603100RFKEA
R20: 1.2M; R_0603_1608Metric; MPN CRCW06031M20FKEA
R21: 200k; R_0603_1608Metric; MPN CRCW0603200KFKEA
SW1: SW_SPDT; SW_SPDT_CK_JS102011SAQN; MPN JS102011SAQN
TP1, TP2, TP3: TestPoint_Small; TestPoint_Pad_D1.5mm
U1: TPS7A2033PDBVR; SOT-23-5; MPN TPS7A2033PDBVR
U2: BQ24074RGT; VQFN-16-1EP_3x3mm_P0.5mm_EP1.6x1.6mm; MPN BQ24074RGTR
U3: TPS7A94; TPS7A94_WSON-10; MPN TPS7A9401DSCR
U4: TPS7A39; Texas_S-PVSON-N10_ThermalVias; MPN TPS7A3901DSCR
U5: TPS65132W; TPS65132W_WQFN-20-TI; MPN TPS65132WRVCR
U6: TPS63000; Texas_DRC0010J_ThermalVias; MPN TPS63000DRCR

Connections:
5V_USB: C2.1, D1.2 (A), U2.13 (IN); also elsewhere on the board
+3.3V_A: C9.2, FB2.1, R4.2, U3.8 (SNS), U3.9 (OUT), U3.10 (OUT)
+3.3V_D: C4.1, FB1.1, U1.5 (OUT)
+3.3V_TAC_A: C10.1, C11.1, R5.2, TP3.1 (1_1); also elsewhere on the board
+3.3V_TAC_D: C5.1, C6.1, R1.2, TP1.1 (1_1); also elsewhere on the board
+3.5V: C3.1, C34.1, C35.1, C36.1, FB7.1, R20.1, U1.1 (IN), U1.3 (EN), U6.1 (VOUT)
+3.5V_ESP: C37.1, C38.1, FB7.2, TP2.1 (1_1); also elsewhere on the board
+5.5V: C17.1, C20.1, U4.1 (INP), U4.2 (EN), U5.15 (OUTP), U5.16 (OUTP)
+5V: C8.2, C13.1, C14.1, FB3.1, FB5.1, R12.1, U3.1 (IN), U3.2 (IN), U3.3 (EN_UV), U4.10 (OUTP)
+5V_DRL: C29.1, C30.1, R17.2; also elsewhere on the board
+5V_InAmp: C15.1, C16.1, R11.2; also elsewhere on the board
-5.5V: C21.1, C22.1, U4.5 (INN), U5.9 (OUTN)
-5V: C23.2, C25.1, FB4.1, FB6.1, R15.2, U4.6 (OUTN)
-5V_DRL: C31.1, C32.1, R18.2; also elsewhere on the board
-5V_InAmp: C26.1, C27.1, R16.2; also elsewhere on the board
GNDA: C8.1, C9.1, C10.2, C11.2, C12.2, C14.2, C15.2, C16.2, C17.2, C19.1, C22.2, C25.2, C26.2, C27.2, C29.2, C30.2, C31.2, C32.2, J3.1 (Pin_1_1), NT1.2, R3.1, R10.2, R13.2, U3.4 (PG), U3.6 (GND), U3.11 (Thermal_Pad), U4.4 (GND), U4.11 (GND); also elsewhere on the board
GNDD: C1.2, C2.2, C3.2, C4.2, C5.2, C6.2, C7.2, C18.2, C20.2, C21.2, C24.2, C33.2, C35.2, C36.2, C37.2, C38.2, C39.2, J1.2, J2.1 (Pin_1_1), NT1.1, R6.2, R7.2, R8.2, R9.2, R21.2, U1.2 (GND), U1.4 (Pad), U2.4 (~CE), U2.6 (EN1), U2.8 (VSS), U2.14 (TMR), U2.17 (VSS), U5.1 (PGND), U5.2 (PGND), U5.3 (AGND), U5.11 (PGND), U5.12 (PGND), U5.17 (AGND), U5.21 (PAD), U6.3 (PGND), U6.9 (GND), U6.11 (PGND); also elsewhere on the board
I2C_SCL: U5.8 (SCL); also elsewhere on the board
I2C_SDA: U5.7 (SDA); also elsewhere on the board
unnamed: C24.1, U5.14 (REG), U5.18 (REG)
unnamed: D1.1 (K), R2.1
unnamed: FB1.2, R1.1
unnamed: FB2.2, R5.1
unnamed: FB3.2, R11.1
unnamed: FB4.2, R16.1
unnamed: FB5.2, R17.1
unnamed: FB6.2, R18.1
unnamed: J1.1, SW1.2 (B)
unnamed: L1.2, U5.19 (SW), U5.20 (SW)
unnamed: R8.1, U2.12 (ILIM)
unnamed: R7.1, U2.16 (ISET)
unnamed: R9.1, U2.15 (ITERM)
unnamed: R6.1, U2.1 (TS)
unnamed: R2.2, U2.9 (~CHG)
unnamed: R3.2, R4.1, U3.5 (FB_PG)
unnamed: C12.1, R10.1, U3.7 (NR_SS)
unnamed: R14.1, U4.8 (BUF)
unnamed: C23.1, R14.2, R15.1, U4.7 (FBN)
unnamed: C13.2, R12.2, R13.1, U4.9 (FBP)
unnamed: C19.2, U4.3 (NR/SS)
unnamed: C28.1, U5.13 (CFLY1)
unnamed: C28.2, U5.10 (CFLY2)
unnamed: C39.1, R19.2, U6.6 (EN), U6.7 (PS/SYNC), U6.8 (VINA)
unnamed: C34.2, R20.2, R21.1, U6.10 (FB)
unnamed: L2.1, U6.4 (L1)
unnamed: L2.2, U6.2 (L2)
V_BAT: C7.1, SW1.1 (A), U2.2 (BAT), U2.3 (BAT); also elsewhere on the board
V_IN: C1.1, C18.1, C33.1, L1.1, R19.1, U2.5 (EN2), U2.10 (OUT), U2.11 (OUT), U5.4 (VIN), U5.5 (ENP), U5.6 (ENN), U6.5 (VIN)

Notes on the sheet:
AGND is intentionally connected to GNDD here.

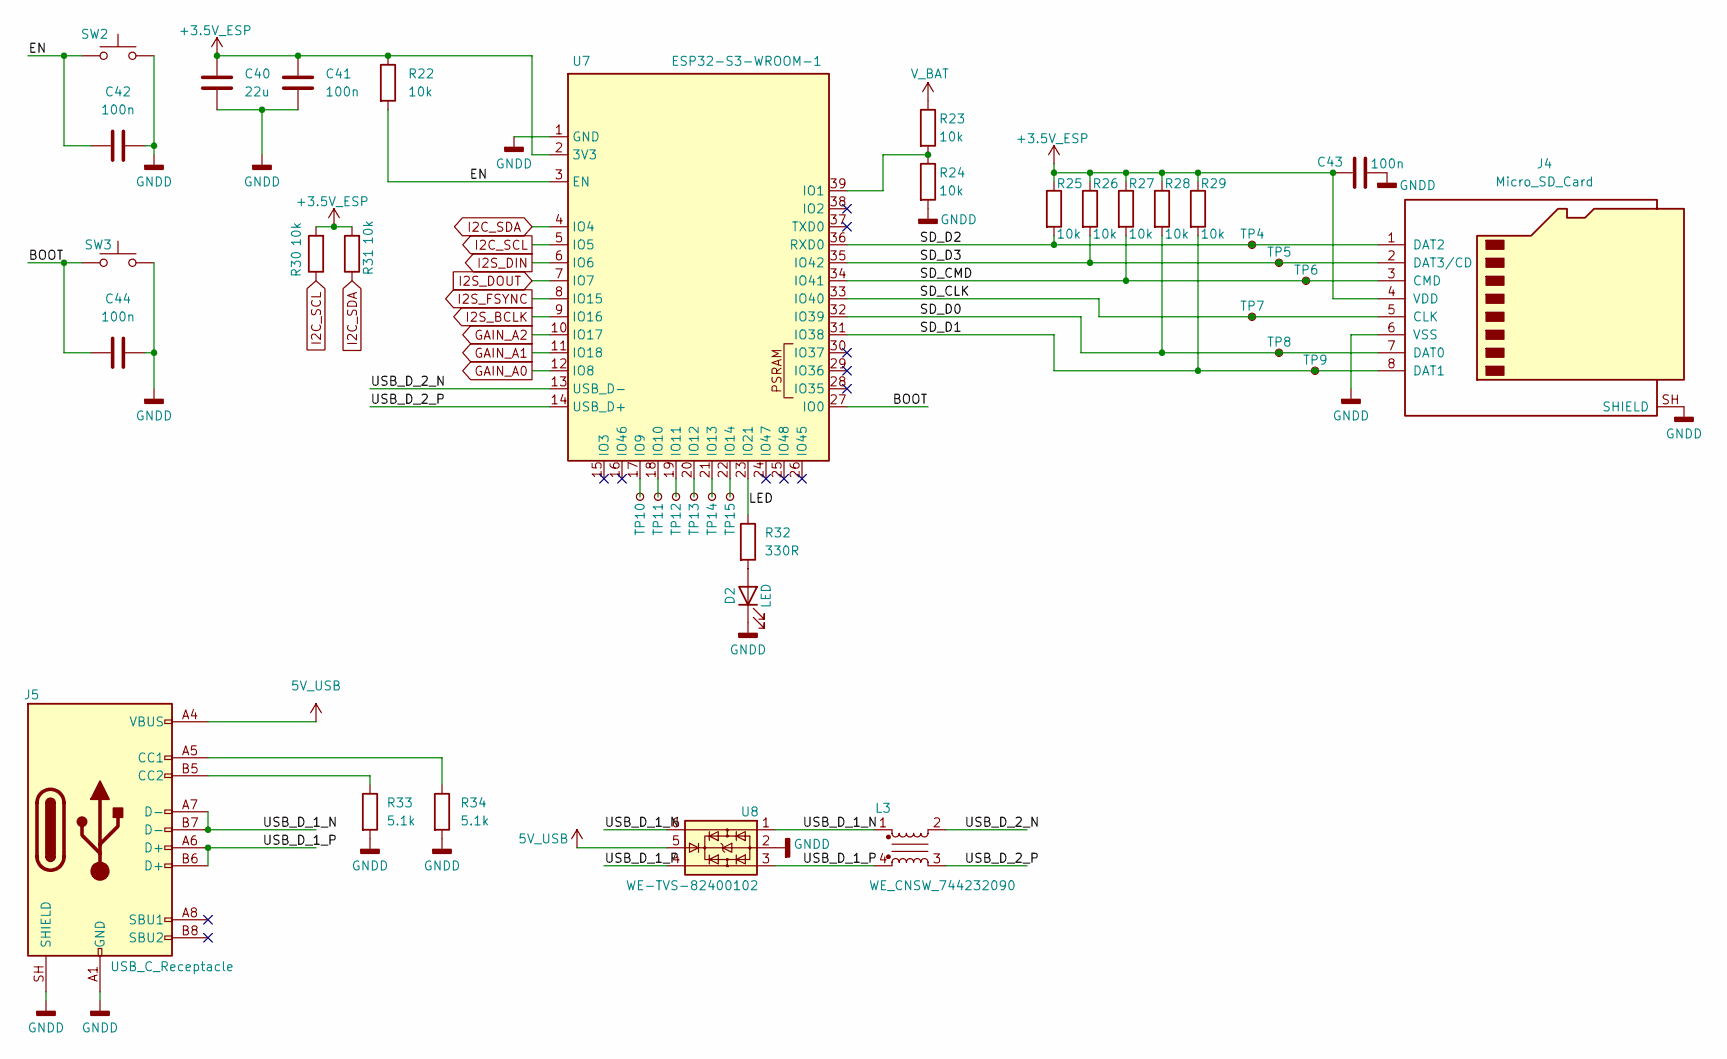
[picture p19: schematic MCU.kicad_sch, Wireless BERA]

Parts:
C40: 22u; C_0805_2012Metric; MPN GRM21BR60J226ME39L
C41, C42, C43, C44: 100n; C_0603_1608Metric; MPN C0603C104K5RACTU
D2: LED; LED_0603_1608Metric; MPN 150060VS75000
J4: Micro_SD_Card; microSD_HC_Wuerth_693072010801; MPN 693072010801
J5: USB_C_Receptacle; USB_C_Receptacle_GCT_USB4105-xx-A_16P_TopMnt_Horizontal; MPN 629722000214
L3: WE_CNSW_744232090; L_CommonMode_Wurth_WE-CNSW-1206; MPN 744232090
R22, R23, R24, R25, R26, R27, R28, R29, R30, R31: 10k; R_0603_1608Metric; MPN CRCW060310K0FKEA
R32: 330R; R_0603_1608Metric; MPN CRCW0603330RFKEA
R33, R34: 5.1k; R_0603_1608Metric; MPN CRCW06035K10FKEA
SW2, SW3: SW_Push; SW_SPST_EVQP2_MiddlePushTravel_H2.5mm; MPN EVQ-P2P02M
TP4, TP5, TP6, TP7, TP8, TP9, TP10, TP11, TP12, TP13, TP14, TP15: TestPoint_Small; TestPoint_Pad_D1.5mm
U7: ESP32-S3-WROOM-1; MPN ESP32-S3-WROOM-1-N16R8
U8: WE-TVS-82400102; SOT-23-6; MPN 82400102

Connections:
5V_USB: J5.A4 (VBUS), J5.A9 (VBUS), J5.B4 (VBUS), J5.B9 (VBUS), U8.5; also elsewhere on the board
+3.5V_ESP: C40.1, C41.1, C43.1, J4.4 (VDD), R22.1, R25.1, R26.1, R27.1, R28.1, R29.1, R30.2, R31.2, U7.2 (3V3); also elsewhere on the board
/MCU/BOOT: C44.1, SW3.1, U7.27 (IO0)
/MCU/EN: C42.1, R22.2, SW2.1, U7.3 (EN)
/MCU/LED: R32.1, U7.23 (IO21)
/MCU/SD_CLK: J4.5 (CLK), TP7.1 (1_1), U7.33 (IO40)
/MCU/SD_CMD: J4.3 (CMD), R27.2, TP6.1 (1_1), U7.34 (IO41)
/MCU/SD_D0: J4.7 (DAT0), R28.2, TP8.1 (1_1), U7.32 (IO39)
/MCU/SD_D1: J4.8 (DAT1), R29.2, TP9.1 (1_1), U7.31 (IO38)
/MCU/SD_D2: J4.1 (DAT2), R25.2, TP4.1 (1_1), U7.36 (RXD0)
/MCU/SD_D3: J4.2 (DAT3/CD), R26.2, TP5.1 (1_1), U7.35 (IO42)
/MCU/USB_D_1_N: J5.A7 (D-), J5.B7 (D-), L3.1, U8.1, U8.6
/MCU/USB_D_1_P: J5.A6 (D+), J5.B6 (D+), L3.4, U8.3, U8.4
/MCU/USB_D_2_N: L3.2, U7.13 (USB_D-)
/MCU/USB_D_2_P: L3.3, U7.14 (USB_D+)
GAIN_A0: U7.12 (IO8); also elsewhere on the board
GAIN_A1: U7.11 (IO18); also elsewhere on the board
GAIN_A2: U7.10 (IO17); also elsewhere on the board
GNDD: C40.2, C41.2, C42.2, C43.2, C44.2, D2.1 (K), J4.6 (VSS), J4.SH (SHIELD), J5.A1 (GND), J5.A12 (GND), J5.B1 (GND), J5.B12 (GND), J5.SH (SHIELD), R24.2, R33.2, R34.2, SW2.2, SW3.2, U7.1 (GND), U7.40 (GND), U7.41 (GND), U8.2; also elsewhere on the board
I2C_SCL: R30.1, U7.5 (IO5); also elsewhere on the board
I2C_SDA: R31.1, U7.4 (IO4); also elsewhere on the board
I2S_BCLK: U7.9 (IO16); also elsewhere on the board
I2S_DIN: U7.6 (IO6); also elsewhere on the board
I2S_DOUT: U7.7 (IO7); also elsewhere on the board
I2S_FSYNC: U7.8 (IO15); also elsewhere on the board
unnamed: D2.2 (A), R32.2
unnamed: J5.A5 (CC1), R34.1
unnamed: J5.B5 (CC2), R33.1
unnamed: R23.2, R24.1, U7.39 (IO1)
unnamed: TP10.1 (1_1), U7.17 (IO9)
unnamed: TP11.1 (1_1), U7.18 (IO10)
unnamed: TP12.1 (1_1), U7.19 (IO11)
unnamed: TP13.1 (1_1), U7.20 (IO12)
unnamed: TP14.1 (1_1), U7.21 (IO13)
unnamed: TP15.1 (1_1), U7.22 (IO14)
V_BAT: R23.1; also elsewhere on the board

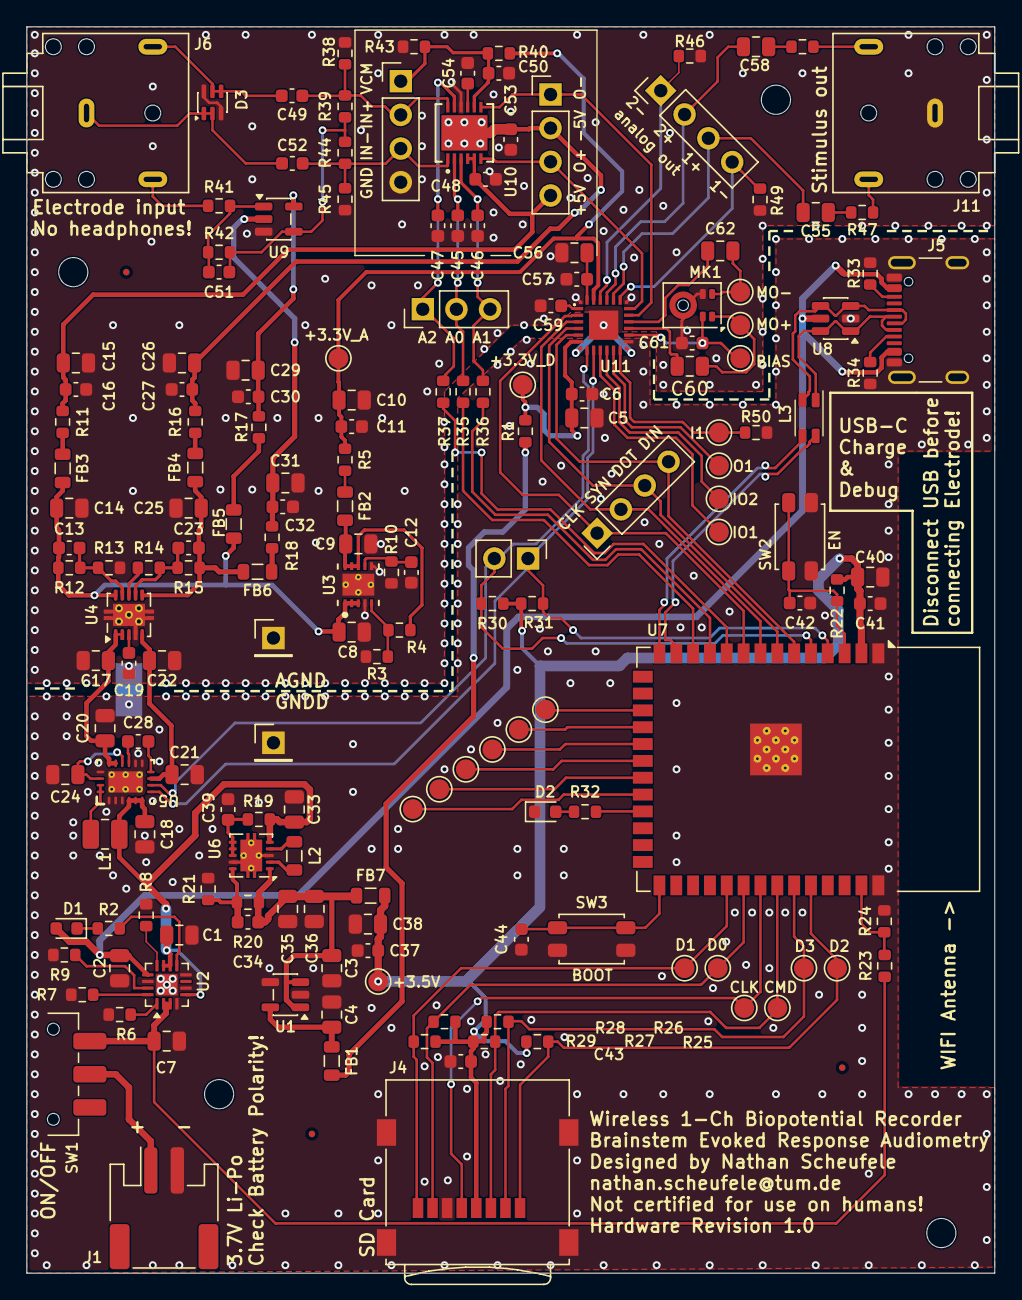
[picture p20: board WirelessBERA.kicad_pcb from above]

Board: 4 copper layers, 73.0 x 94.0 mm, 183 parts (1 on the bottom side), 111 nets.

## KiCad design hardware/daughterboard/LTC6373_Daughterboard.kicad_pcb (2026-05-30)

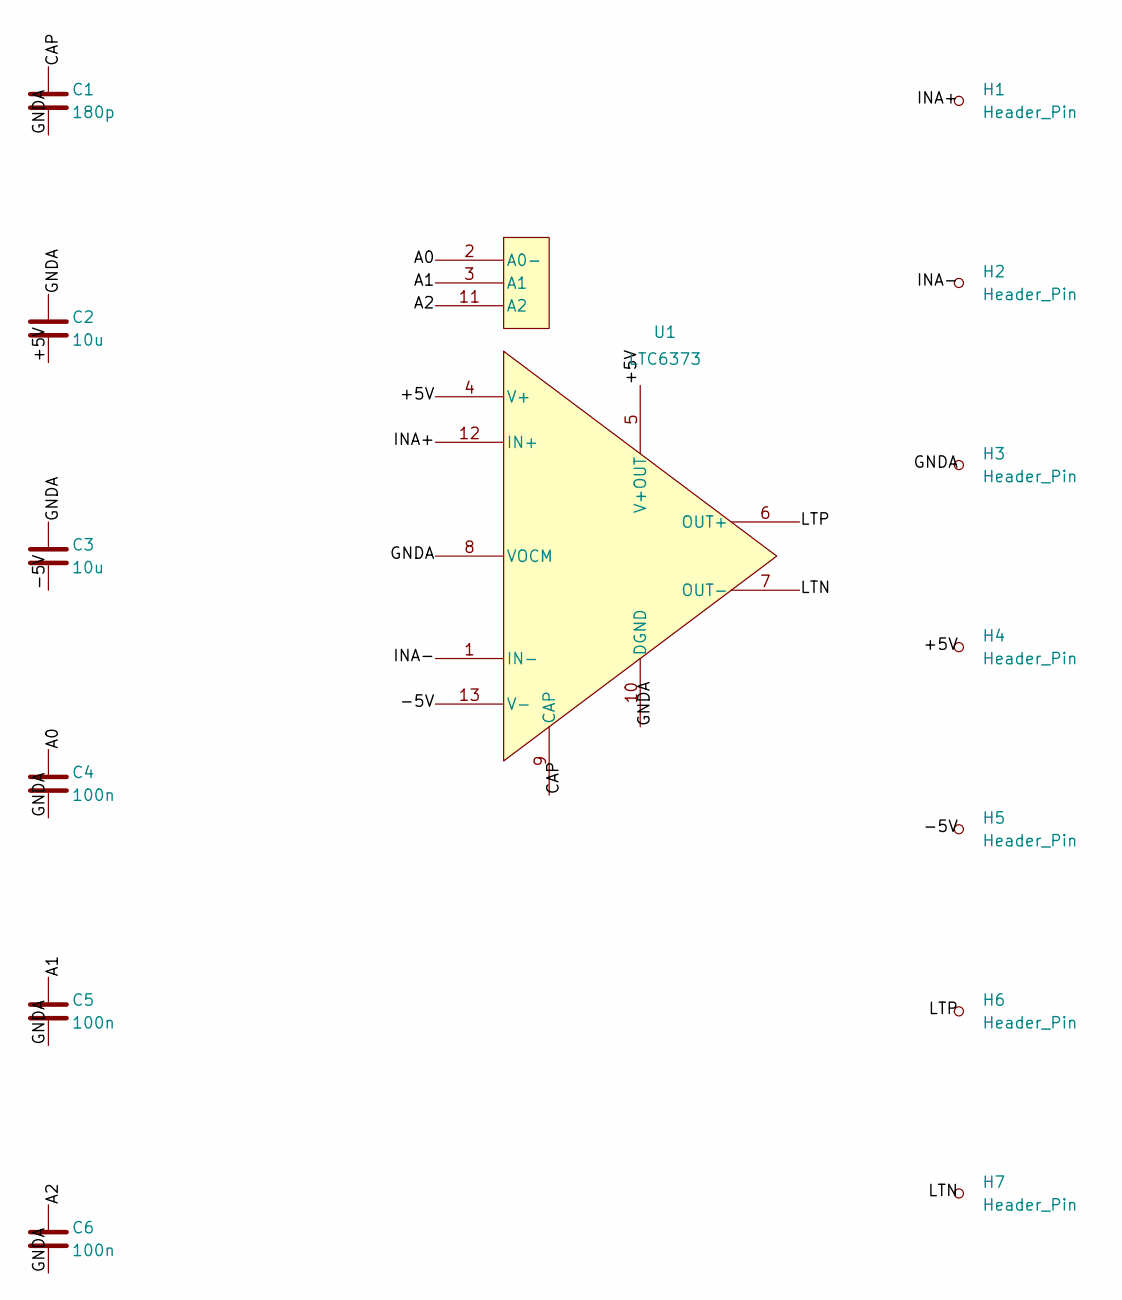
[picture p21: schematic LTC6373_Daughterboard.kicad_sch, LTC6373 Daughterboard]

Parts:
C1: 180p; C_0603_1608Metric
C2, C3: 10u; C_0603_1608Metric
C4, C5, C6: 100n; C_0603_1608Metric
H1, H2, H3, H4, H5, H6, H7: Header_Pin; TestPoint_Loop_D2.60mm_Drill0.9mm_Beaded
U1: LTC6373; LTC6373_DFN-12

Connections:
+5V: C2.2, H4.1 (1_1), U1.4 (V+), U1.5 (V+OUT)
-5V: C3.2, H5.1 (1_1), U1.13 (V-)
A0: C4.1, U1.2 (A0-)
A1: C5.1, U1.3 (A1)
A2: C6.1, U1.11 (A2)
CAP: C1.1, U1.9 (CAP)
GNDA: C1.2, C2.1, C3.1, C4.2, C5.2, C6.2, H3.1 (1_1), U1.8 (VOCM), U1.10 (DGND)
INA+: H1.1 (1_1), U1.12 (IN+)
INA-: H2.1 (1_1), U1.1 (IN-)
LTN: H7.1 (1_1), U1.7 (OUT-)
LTP: H6.1 (1_1), U1.6 (OUT+)

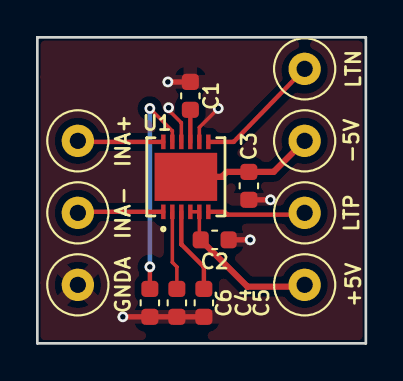
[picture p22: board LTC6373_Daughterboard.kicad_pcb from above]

Board: 2 copper layers, 18.2 x 17.0 mm, 14 parts (0 on the bottom side), 11 nets.

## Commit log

2026-05-30 v1.0 Release: Stacked daughterboard alignment & clean renderings
    [Analog.kicad_sch, BOM_Daughterboard.csv, LTC6373.step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]
2026-06-03 Changed Pinheader and found a Problem with V0CM.
    [Analog.kicad_sch, MCU.kicad_sch, Power.kicad_sch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]
2026-06-03 Release: First PCB manufacturing batch. Fixed U10 thermal via short, exempted fiducials from solder mask margin override rule, adjusted R22 label, and updated all manufacturing files.
    [Analog.kicad_sch, Mouser_DigiKey_BOM_Upload.csv, Mouser_Order.csv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]
2026-06-03 Version 1.0 ordered at Aisler. Waiting for PCBs to arrive.
    [WirelessBERA.kicad_pcb]
2026-06-03 BOM Update: Replace C48 and C53 with Mouser part GRM188R61C106MA73J and update all exports.
2026-09-17 New firmware: browser-operated ADC/DAC, AP + client Wi-Fi
    Replaces the esp_blink prototype with firmware/wireless_bera/, written from
    the schematic netlist and the part datasheets rather than from the old code.
    Verified on the assembled v1.0 board:
    - TAC5212 at I2C 0x50, PLL locked off BCLK, BCLK:FSYNC = 64, no clock
    errors at 8/16/24/32/48/96 kHz
    - both ADC channels streaming; CH2 shows 50.05 Hz mains pickup with
    150/250 Hz harmonics (~141 uV referred to the input) through the open
    electrode jack, which confirms the whole analog chain
    - AP and station up simultaneously, mDNS, IPv6 link-local
    - TPS65132W rails read back at +/-5.4 V, codec AVDD monitor at 3.31 V
    Structur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
2026-09-17 v1.0: tidy the repository and bring the documentation up to date
    The tree is now hardware, firmware and docs, and nothing else.
    Removed (all of it untracked or regenerable):
    - firmware/esp_blink - the prototype firmware the new one replaces
    - scratch/ - 87 one-off analysis scripts
    - hardware/.history/ and hardware/WirelessBERA-backups/ - editor undo
    history and KiCad autosaves, 146 MB between them
    - docs/datasheets/ - a strict subset of hardware/datasheets, so 19 vendor
    PDFs were stored twice
    - build output, __pycache__, .DS_Store, a drawio autosave
    Moved into hardware/, where they belong:
    - manufacturing/ -> hardware/manufacturing/
    - simulation_temp/ -> hardware/simu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
2026-10-16 Add assembly photos and first ECG/DRL measurements
    - docs/images/assembly: bare PCB, stencil printing, placement and the
    assembled board (resized to 1600 px)
    - measurements/2026-10-16_ecg_drl: three 60 s chest-ECG recordings
    (no DRL, DRL via hand, DRL via chest electrode) as raw int16 CSV,
    with setup, scaling and results. DRL lowers 50 Hz pickup by 10-18 dB.
    - measurements/tools: WebSocket recorder and the analysis script
    Channel 2 is polarity-inverted on the board (LTC6373 OUT- -> IN2P);
    the README and the analysis script account for it.
2026-10-16 Add repeated chest-DRL ECG recording
    A fourth 60 s recording with the DRL lead on the chest electrode, taken a
    few minutes after the first. 50 Hz pickup is 12 dB below the no-DRL case
    (first chest run: 10 dB, hand: 18 dB). README table and figure updated.
2026-10-16 Add BERA measurements, analysis tools and v1.0 report
    - First click ABR runs (incl. sham and earbud-out controls), electrode photo
    - Apple Watch ECG comparison, beat morphology, failed EEG attempt
    - Recording/analysis scripts for BERA, EEG/EOG/EMG, heart, artefacts, mic
    - Rebuilt technical report (report/) with figures and PDF
